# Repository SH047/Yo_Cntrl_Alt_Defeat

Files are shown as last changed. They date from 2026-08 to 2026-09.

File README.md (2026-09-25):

# WRO 2026 Future Engineers

## Team YO_CNTRL_ALT_DEFEAT - Version 2

| | |
| --- | --- |
| **Team name** | YO_CNTRL_ALT_DEFEAT |
| **Team ID** | 1680 |
| **Team members** | Abhay and Nidhella |
| **Country / region** | India |
| **Season** | 2026 - Future Engineers |

This repository documents Version 2 of the YO_CNTRL_ALT_DEFEAT autonomous vehicle for WRO Future Engineers. V2 is a rear-wheel-drive vehicle with servo-driven front-wheel steering and a mechanical rear differential. A **single ESP32 DevKit V1** runs every real-time task. It reads three VL53L0X time-of-flight (ToF) sensors (plus an optional rear sensor) through a TCA9548A I2C multiplexer, takes heading from a BNO055 IMU, measures distance from a quadrature encoder on a JGB37-520 geared motor, and drives the steering servo and motor driver. Colour recognition is handled on board by a **HUSKYLENS AI camera**, which reports coloured blocks to the ESP32 over I2C. No separate vision computer is carried on V2.

## V1 baseline

<p align="center">
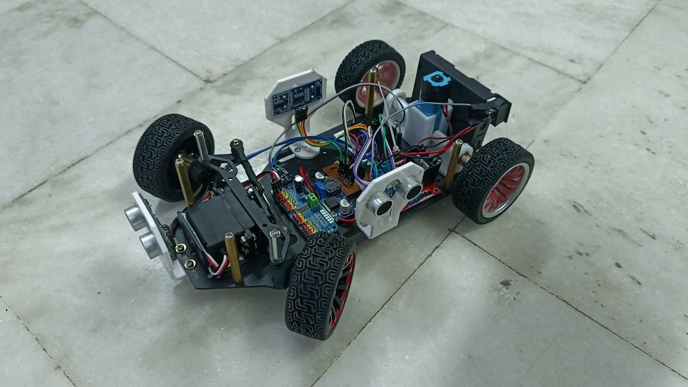
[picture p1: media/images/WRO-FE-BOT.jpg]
YO_CNTRL_ALT_DEFEAT Version 1 robot
  
</p>

<p align="center"><em>Version 1 prototype. This image remains as the visual baseline for the V2 design record.</em></p>

| Area | V2 implementation | Measured evidence |
| --- | --- | --- |
| Mobility | Rear-wheel drive through a mechanical differential, servo-driven front-wheel steering | Open round 23/25 successful runs; heading error after each corner ±2-4° |
| Feedback | Quadrature encoder, BNO055 IMU, 3 × VL53L0X ToF (+1 optional rear) | Encoder calibration ±2 ticks per metre; ToF ±7-10 cm at 2 m |
| Compute | Single ESP32 DevKit V1 + HUSKYLENS AI camera (on-camera colour recognition) | Start-up device check; pillar pass rate 44/50 |
| Fabrication | Acrylic chassis plate with 3D-printed PETG mounts from the STL library | Fitted STL set recorded in the engineering documentation (§2.6) |

## Documentation

| Resource | Purpose |
| --- | --- |
| [Engineering documentation](docs/) | Full V2 engineering documentation (PDF): design rationale, pin map, calibration, strategy, test results |
| [V2 engineering journal](docs/V2_ENGINEERING_JOURNAL.md) | Design rationale, V1-to-V2 change log, risks and validation plan |
| [`Codes/`](Codes/) | Competition programs for the open and obstacle rounds (ESP32) |
| [V2 STL library](hardware/STL_V2/) | 31 supplied STL files and fabrication notes |
| [V2 electronics reference](hardware/ELECTRONICS_V2/) | Component architecture, wiring rules and bench-test worksheet |
| [Bill of materials](hardware/) | `Yo_Cntrl_Alt_Defeat BOM.csv` |
| [Robot photographs](media/images/v2/) | V2 robot views and wiring photograph |
| [Mock run video](media/videos/) | `v2-MockRun-OpenRound.mp4` |
| [`src/`](src/) | Earlier code snapshots |

## V2 system architecture

```mermaid
flowchart LR
    Husky["HUSKYLENS AI camera<br/>On-camera colour recognition"] -->|"I2C: colour blocks (x, y, w, h, ID)"| ESP["ESP32 DevKit V1<br/>Sensing, decisions and actuation"]
    ESP <-->|I2C| Mux["TCA9548A<br/>I2C multiplexer (0x70)"]
    Mux -->|ch 0| ToF1[Front ToF]
    Mux -->|ch 1| ToF2[Right ToF]
    Mux -->|ch 2| ToF3[Left ToF]
    Mux -->|ch 3| IMU["BNO055 IMU<br/>Absolute heading"]
    Mux -.->|"ch 6 (optional)"| ToF4[Rear ToF]
    ESP -->|GPIO 13| Servo["RoboKit 20 kg<br/>steering servo"]
    ESP -->|"GPIO 26 PWM / 27 DIR"| Driver["7 Semi Vikram<br/>motor driver"]
    Driver --> Motor["JGB37-520 geared motor<br/>Quadrature encoder"]
    Motor -->|"Encoder A/B: GPIO 18 / 19"| ESP
    Start["START button"] -->|GPIO 25| ESP
    ESP -->|GPIO 14| Ring["NeoPixel ring<br/>Status"]
    ESP -.->|Bluetooth CSV log| Phone["Phone<br/>YoLabs-FE"]
```

V2 has one programmable controller. The HUSKYLENS is treated as a smart sensor: it captures frames, runs the trained colour-recognition model, and returns a short list of coloured blocks with their position, size and learned ID. The ESP32 requests these blocks every loop, filters them by shape, reads the ToF sensors, IMU and encoder, runs the open-round and obstacle-round state machines, drives the servo and motor, and logs every loop over Bluetooth.

## V1 and V2 comparison

| Area | V1 prototype | V2 robot | Why it matters |
| --- | --- | --- | --- |
| Vision | Separate vision computer + camera with OpenCV, commands sent over UART | HUSKYLENS AI camera on the ESP32 I2C bus | One controller owns the whole decision; no serial link to fail; colour model trained on the field |
| Distance sensing | Three HC-SR04 ultrasonic sensors, 5 V ECHO dividers | 3 × VL53L0X ToF (+ optional rear) via TCA9548A | Narrow beam, 3.3 V native, continuous ranging, no level shifting |
| Drive | BO motor, time-based distance | JGB37-520 geared motor + quadrature encoder, rear differential | Distance in millimetres; stall detection; smoother cornering |
| Heading | Basic / none | BNO055 absolute heading with PD control | Straight legs and exact 90° corners |
| Power | 9 V supply, one buck converter | 12 V LiPo, separate motor, servo and logic branches | Motor and servo surges kept off the logic rail |
| Run feedback | USB serial only | Bluetooth CSV log ("YoLabs-FE") + NeoPixel status ring | Every practice run produces data for tuning |
| Mechanical platform | Prototype steering chassis | Acrylic chassis plate with 3D-printed PETG mounts and bearing supports | Improved alignment and easier component replacement |

## Advantages of V2

1. The encoder and BNO055 IMU make every manoeuvre distance- and heading-based, so battery voltage no longer changes where the robot turns.
2. Narrow-beam ToF sensors at the front, left and right (plus an optional rear sensor) measure the wall they point at, not the nearest object in a wide acoustic cone.
3. The rear differential lets each rear wheel turn at its own speed in corners, reducing tyre scrub and heading disturbance with only one motor, one driver and one encoder.
4. Separate motor, servo and logic power branches stop motor or steering surges from browning out the ESP32 or the HUSKYLENS.
5. Moving colour recognition into the HUSKYLENS removes the second computer, its boot sequence and the serial link, so there are fewer failure points at the start line.
6. Colours are learned on the actual field with a button press, so re-training under venue lighting takes minutes.
7. Every loop is logged as a CSV line over Bluetooth, so each practice run leaves data for tuning.

## Hardware list

| Item | Qty | Role in the robot |
| --- | --- | --- |
| HUSKYLENS AI camera | 1 | Colour recognition of red / green traffic signs and blue / orange corner lines |
| ESP32 DevKit V1 | 1 | Single real-time controller; Bluetooth logging |
| VL53L0X time-of-flight sensor | 3 (+1) | Front, right and left distance; optional rear sensor for corner reverse |
| TCA9548A I2C multiplexer | 1 | Gives each same-address VL53L0X (and the IMU) its own channel |
| BNO055 9-axis IMU | 1 | Absolute heading for straight-line and corner control |
| JGB37-520 DC geared motor (120 RPM) | 1 | Rear-wheel propulsion |
| Quadrature motor encoder | 1 | Distance travelled and stall detection |
| Mechanical differential + drive shafts | 1 + 2 | Splits drive to the rear wheels while allowing different speeds in turns |
| RoboKit 20 kg high-torque servo | 1 | Front-wheel steering |
| 7 Semi Vikram motor driver | 1 | PWM speed and direction control of the drive motor |
| 12 V LiPo battery | 1 | Primary energy source (XT60 connector) |
| Voltage regulators (5 V logic, servo) | 2 | Separate logic and servo supplies |
| WS2812B NeoPixel ring, 16 LED | 1 | Run-state and fault indication |
| START push-button, power switch | 1 + 1 | Run start / stop; master isolation |
| Wheels / tyres | 4 | Traction (large rear, small front) |
| Acrylic chassis plate + 3D-printed mounts | 1 set | Structure |
| Jumper wires, power cables, perfboard | as required | Interconnection |

## Image record
> **V2 front-left view**<br>
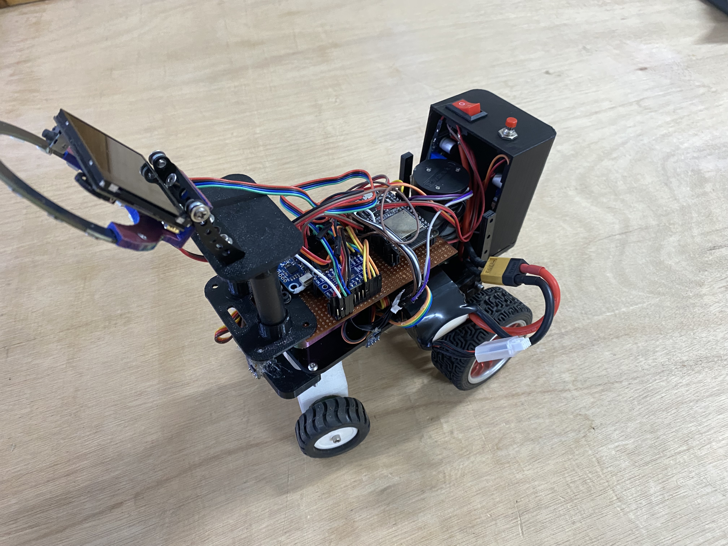
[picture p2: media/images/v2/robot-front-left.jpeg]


> **V2 top view**<br>
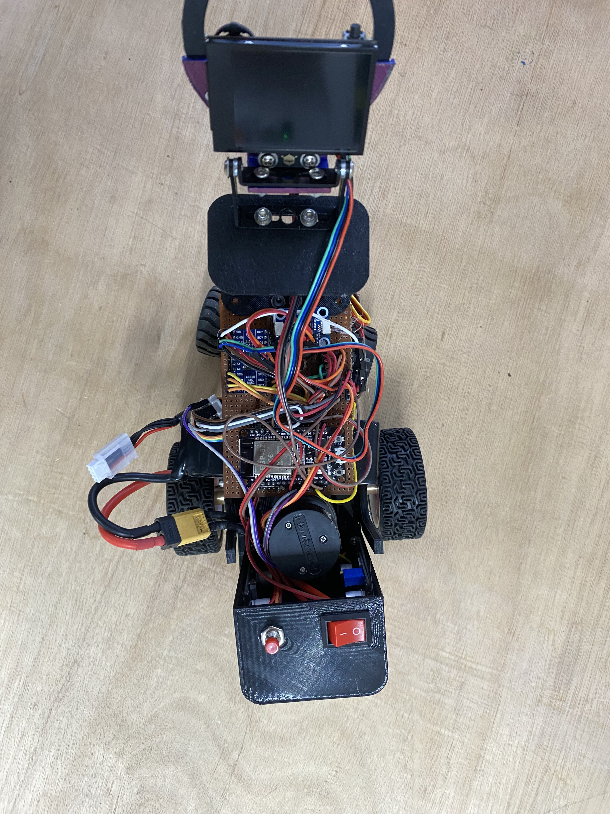
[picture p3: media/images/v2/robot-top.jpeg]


> **V2 right-side view**<br>
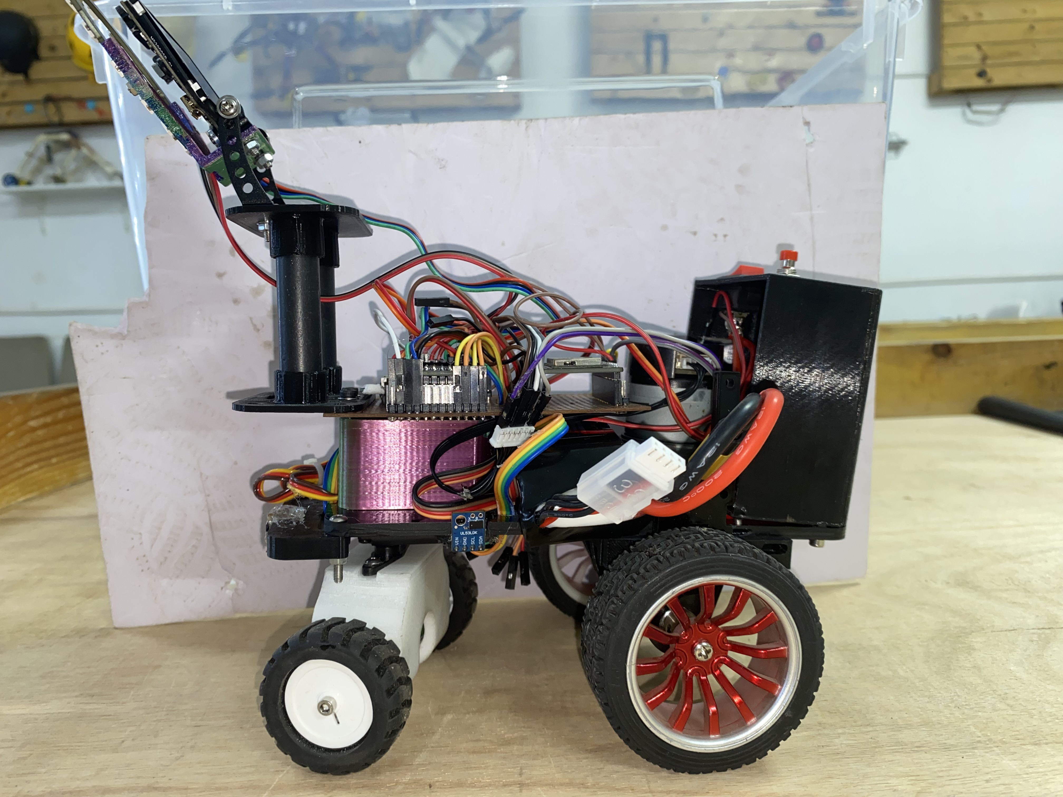
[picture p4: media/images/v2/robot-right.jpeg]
 

> **V2 back**<br>
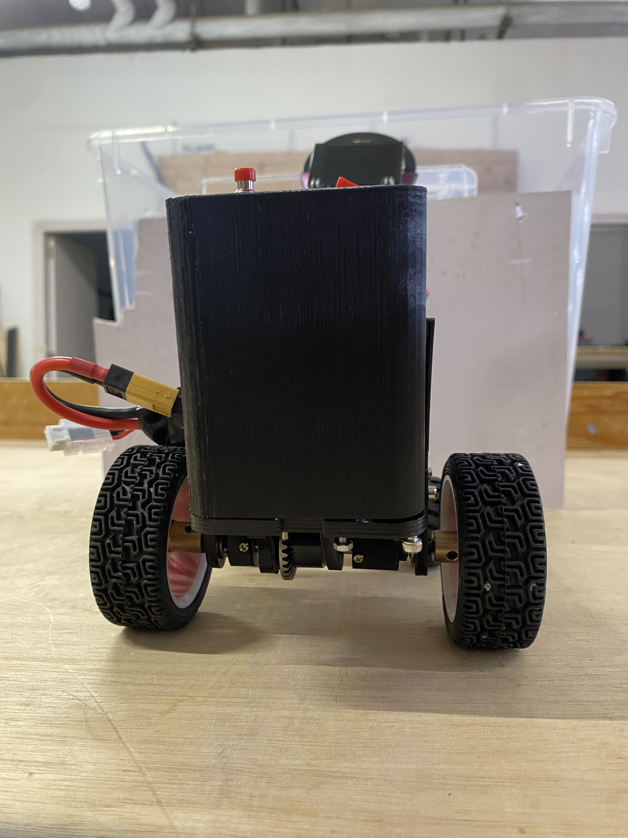
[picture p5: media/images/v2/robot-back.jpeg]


> **V2 wiring view**<br>
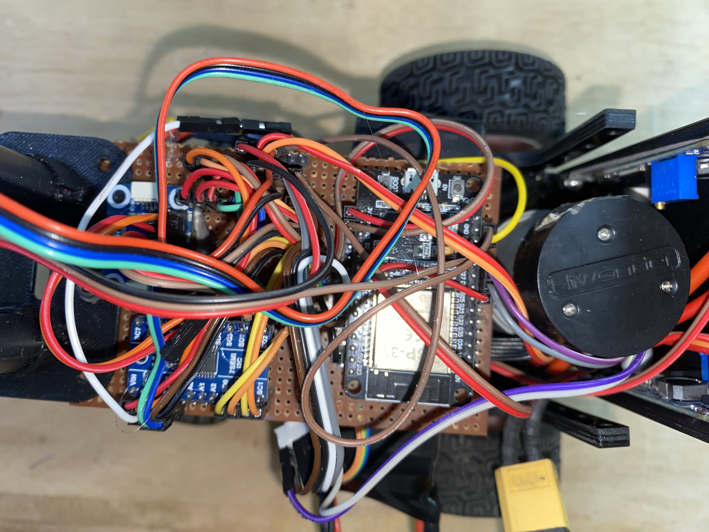
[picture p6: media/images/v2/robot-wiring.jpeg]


## Electrical power flow

```mermaid
flowchart TD
    Battery["12 V LiPo (XT60)"] --> Fuse[Main fuse and power switch]
    Fuse --> MotorRail[Motor branch]
    Fuse --> ServoReg[Servo regulator]
    Fuse --> LogicReg[5 V logic regulator]
    LogicReg --> ESP["ESP32 DevKit V1 (VIN)"]
    LogicReg --> Husky[HUSKYLENS]
    LogicReg --> Ring[NeoPixel ring]
    ESP --> SensorRail["3.3 V from ESP32 regulator"]
    SensorRail --> Mux[TCA9548A]
    SensorRail --> IMU[BNO055]
    SensorRail --> ToF["VL53L0X ToF × 3 (+1)"]
    MotorRail --> Driver[7 Semi Vikram motor driver]
    Driver --> Motor[JGB37-520 geared motor]
    ServoReg --> Servo[20 kg steering servo]
    Ground[Single common ground node] --- MotorRail
    Ground --- ServoReg
    Ground --- LogicReg
```

The servo is never powered from the ESP32 or from the 5 V logic rail, because a 20 kg servo stalling at full lock can pull enough current to brown out the ESP32 and reset the run. Battery, motor driver, both regulators, ESP32, servo, HUSKYLENS and all I2C sensors share one ground node. Before integration, verify polarity, measure each regulator output with no load, and confirm that every I2C device answers while PWM is active.

## ESP32 pin assignment

| Component | Connection | ESP32 pin |
| --- | --- | --- |
| Motor driver IN1 | Speed / PWM | GPIO 26 |
| Motor driver IN2 | Direction | GPIO 27 |
| Steering servo | Signal (50 Hz PWM, 500-2400 µs) | GPIO 13 |
| Encoder channel A | Interrupt, rising edge | GPIO 18 |
| Encoder channel B | Direction input | GPIO 19 |
| START button | Input, internal pull-up, active low | GPIO 25 |
| NeoPixel ring | Data in | GPIO 14 |
| I2C SDA | HUSKYLENS + TCA9548A | GPIO 21 (default) |
| I2C SCL | HUSKYLENS + TCA9548A | GPIO 22 (default) |
| Common ground | GND | ESP32 GND |

SDA / SCL are not set explicitly in the code (`Wire.begin()`), so the DevKit V1 defaults GPIO 21 / 22 apply. The I2C bus runs at 100 kHz.

**TCA9548A channels:** ch 0 → front ToF, ch 1 → right ToF, ch 2 → left ToF, ch 3 → BNO055, ch 6 → rear ToF (optional). The HUSKYLENS sits on the main bus, which stays connected whatever channel is selected.

## HUSKYLENS colour IDs

| ID | Colour | Field element | Used for |
| --- | --- | --- | --- |
| 1 | Blue | Corner line | Corner confirmation (line gate) |
| 2 | Orange | Corner line | Corner confirmation (line gate) |
| 3 | Magenta | Parking-lot marker | Logged only |
| 4 | Red | Traffic sign | Pass on the right |
| 5 | Green | Traffic sign | Pass on the left |

Learn each colour ID on the actual field under the venue lighting before running.

## Program set

Each round has its own program in [`Codes/`](Codes/), so a change for one round cannot break the other. All tuning constants are `#define` values at the top of each program.

| File | Round | Status | Summary |
| --- | --- | --- | --- |
| `01_Complete_Open_Round_CW_CCW.ino` | Open | Competition | Heading PD + wall centring, ToF corner detection, auto CW / CCW lock, 12 turns then finish |
| `03_Obstacle_Round_With_Parking_Out_Corrected.ino` | Obstacle | Competition | Parking exit, pillar bulges, gated precision corners, optional rear-ToF reverse |
| `02_Obstacle_Round_No_Parking_Slow_Accurate.ino` | Obstacle | Fallback | Same strategy at PWM 70, no parking exit |

To flash a program, open the `.ino` file in the Arduino IDE with ESP32 board support, select the ESP32 DevKit V1 board, install the libraries listed in the program header (including the DFRobot HUSKYLENS library), and upload over USB.

## Control flow

```mermaid
flowchart TD
    Start[Power on] --> Check["Start-up device check:<br/>ToF channels, BNO055, HUSKYLENS"]
    Check -->|"Sensor missing"| Fault["Flash ring yellow, log channel,<br/>refuse to start"]
    Check -->|"HUSKYLENS not found"| Retry[Retry every 500 ms] --> Check
    Check -->|"Ready (ring warm white)"| Wait[Wait for START button]
    Wait --> Sense["Read HUSKYLENS blocks, ToF,<br/>BNO055 heading and encoder"]
    Sense --> Decide["Phase state machine:<br/>steering and speed target"]
    Decide --> Actuate[ESP32 sets servo angle and motor PWM]
    Actuate --> Log[Write CSV line over Bluetooth]
    Log --> Complete{"12 corners done<br/>and finish section driven?"}
    Complete -->|No| Sense
    Complete -->|Yes| Stop[Stop]
    Sense -->|"Obstacle round: front ToF ≤ 12 cm<br/>with corner gates failing"| Stop
```

The camera decides **what** to do (which side to pass a pillar, whether a corner line is present). The ToF sensors and encoder decide **when** and **whether it is safe**: a camera detection cannot start a corner without the distance, side and front gates, and the front ToF can stop the run whatever the camera sees.

## Measured test results

| Test | Method | Metric | Result |
| --- | --- | --- | --- |
| ToF accuracy | Flat target at a known distance of 2 m | Error in cm per channel | ±7-10 cm |
| Encoder calibration | Push 1 m along a straight edge | Ticks per metre | ±2 |
| Straight-line hold | Drive 2 m on heading PD | Lateral drift (°) | 5-10° |
| Corner accuracy | 12 corners in the open round | Heading error after each turn (°) | ±2-4° |
| Open-round reliability | Repeated full runs, CW and CCW | Successful runs / attempts | 23/25 |
| Pillar pass rate | Red and green pillars at all positions | Correct-side passes / attempts | 44/50 |
| Obstacle-round reliability | Full runs with random layouts | Successful runs / attempts | 12/20 |
| Parking exit | Repeated exits left and right | Clean exits / attempts | 14/15 |

## Build and validation flow

```mermaid
flowchart LR
    A[Select physical components] --> B[Dry-fit STL parts]
    B --> C[Mechanical roll and steering tests]
    C --> D[Power and motor-current tests]
    D --> E[Sensor, camera and Bluetooth-log bench tests]
    E --> F[Short straight and turn tests]
    F --> G[Full-course practice runs]
    G --> H[Freeze working calibration and backup]
```

## Repository structure

```text
README.md                         Main documentation
Codes/                            Competition programs (01, 02, 03) for the ESP32
docs/                             Engineering documentation (PDF) and V2 engineering journal
hardware/ELECTRONICS_V2/          Electronics reference and electrical validation plan
hardware/STL_V2/                  Printable STL parts + README
hardware/Yo_Cntrl_Alt_Defeat BOM.csv  Bill of materials
media/images/v2/                  Robot photographs
media/videos/                     v2-MockRun-OpenRound.mp4
src/                              Earlier code snapshots
```

## Build and bring-up procedure

Following this order means a fault is found while only one subsystem is connected. Section numbers (§) refer to the [engineering documentation](docs/).

1. Assemble the chassis, steering linkage, differential and motor mount; check the wheels turn freely and the steering does not bind at either lock.
2. Wire the common ground first, before any supply rail.
3. Power the regulators alone from the battery and set / measure each output before connecting any load.
4. Connect the ESP32 by USB only; flash a test and confirm Bluetooth logging reaches the phone.
5. Connect the I2C bus: HUSKYLENS, TCA9548A, ToF sensors and BNO055. Flash a program and confirm the start-up check passes (ring turns warm white).
6. Calibrate ToF offsets, encoder ticks per metre and servo centre (§3.9).
7. Learn the colour IDs on the HUSKYLENS on the field (§3.13).
8. With the wheels lifted, check motor direction, encoder sign and servo direction.
9. Run program `01_Complete_Open_Round_CW_CCW.ino` on the field at reduced speed, then at full speed, both directions.
10. Run program `03_Obstacle_Round_With_Parking_Out_Corrected.ino`, first without pillars, then with pillars; record the metrics from the Bluetooth log and note any changes made.

## Before a field run

1. Confirm the fitted STL parts match the actual motor, servo, bearings, differential and sensor boards.
2. Check that the steering has no mechanical bind and the wheels move freely.
3. Check the LiPo voltage, battery polarity (XT60), fuse, common ground and motor-driver current capacity.
4. Re-learn the HUSKYLENS colour IDs under the venue lighting.
5. Power on and confirm the start-up device check passes (ring turns warm white) and the Bluetooth log reaches the phone.
6. Load the saved calibration values and make a backup before changing gains.

## Security and configuration

Keep GitHub tokens, Wi-Fi passwords and event credentials out of tracked files. Use a local ignored configuration file and commit only a placeholder example.

<details>
<summary>V1 prototype reference (historical - superseded by V2 above)</summary>

> This section describes the earlier V1 robot (Raspberry Pi vision, HC-SR04 ultrasonic sensors, BO motor). It is kept for the design record only and does not describe the V2 hardware.

# Obstacle-Avoiding Robot

A rear-wheel-drive autonomous robot with front-wheel steering, three ultrasonic distance sensors, and Raspberry Pi computer vision. The Raspberry Pi uses a camera and OpenCV to detect obstacles/colours and sends high-level commands such as `dodgeRight()` and `dodgeLeft()` to an ESP32 over serial/UART. The ESP32 handles ultrasonic sensing, steering, and motor control.

## 1. System Architecture

```text
                 ┌──────────────────────┐
                 │     RASPBERRY PI     │
                 │                      │
                 │ Camera + OpenCV      │
                 │ Obstacle/colour      │
                 │ decision making      │
                 └──────────┬───────────┘
                            │
                       Serial / UART
                            │
                            ▼
                 ┌──────────────────────┐
                 │        ESP32         │
                 │                      │
                 │ Ultrasonic sensing   │
                 │ Servo steering       │
                 │ Motor control        │
                 └───────┬───────┬──────┘
                         │       │
              ┌──────────┘       └───────────┐
              ▼                              ▼
       ┌─────────────┐                ┌─────────────┐
       │ Servo motor │                │ Motor driver│
       │ Front steer │                │             │
       └─────────────┘                └──────┬──────┘
                                            │
                                            ▼
                                       Rear BO motor
                                       + rear wheels
```

The Raspberry Pi performs high-level visual processing. The ESP32 is responsible for real-time interaction with the physical hardware.

## 2. Main Hardware

- Raspberry Pi
- Raspberry Pi camera module
- ESP32 development board
- 3 × HC-SR04 ultrasonic sensors
- Servo motor for front-wheel steering
- BO motor
- Compatible single-channel motor driver with IN1, IN2 and ENA/PWM inputs
- 9 V battery/supply
- 9 V → 5 V buck converter
- Front steering mechanism and chassis
- Rear wheels connected to the BO motor
- Resistors for ultrasonic ECHO voltage dividers: 1 kΩ and 2 kΩ for each sensor
- Jumper wires and suitable power wiring

## 3. ESP32 Pin Connections

| Component | Connection | ESP32 pin |
|---|---|---|
| Front ultrasonic TRIG | TRIG | GPIO 13 |
| Front ultrasonic ECHO | ECHO | GPIO 34 |
| Left ultrasonic TRIG | TRIG | GPIO 14 |
| Left ultrasonic ECHO | ECHO | GPIO 35 |
| Right ultrasonic TRIG | TRIG | GPIO 25 |
| Right ultrasonic ECHO | ECHO | GPIO 32 |
| Motor driver IN1 | Motor control | GPIO 18 |
| Motor driver IN2 | Motor control | GPIO 19 |
| Motor driver ENA | PWM/speed | GPIO 15 |
| Servo signal | PWM | Use a free suitable GPIO |
| Common ground | GND | ESP32 GND |

GPIO 34 and GPIO 35 are input-only pins, which is appropriate for the ultrasonic ECHO signals.

## 4. Ultrasonic Sensor Wiring

Each HC-SR04 is connected as follows:

```text
HC-SR04 VCC  → 5 V
HC-SR04 GND  → GND
HC-SR04 TRIG → assigned ESP32 GPIO
HC-SR04 ECHO → voltage divider → assigned ESP32 GPIO
```

The HC-SR04 ECHO output can be approximately 5 V, while ESP32 GPIO is designed for 3.3 V logic. Do **not** connect a 5 V ECHO signal directly to an ESP32 input.

Use one voltage divider for every ECHO line:

```text
HC-SR04 ECHO
     │
    1 kΩ
     │
     ├────────────→ ESP32 ECHO GPIO
     │
    2 kΩ
     │
    GND
```

This produces approximately 3.3 V from a 5 V ECHO signal.

Make three identical dividers:

- Front ECHO → GPIO 34
- Left ECHO → GPIO 35
- Right ECHO → GPIO 32

The sensors should be physically positioned so that one faces forward and the other two face left and right.

```text
                    FRONT
                      ↑
                [FRONT SENSOR]

          [LEFT]                 [RIGHT]
          SENSOR                  SENSOR

                 ┌─────────┐
                 │  ROBOT  │
                 └────┬────┘
                      │
                   BO MOTOR
```

## 5. Power System

The 9 V supply powers the motor circuit and is also reduced to 5 V for the servo and ultrasonic sensors.

```text
                 9 V BATTERY
                ┌──────┴──────┐
                │             │
                ▼             ▼
          Motor driver    Buck converter
          motor supply       9 V → 5 V
                              │
                    ┌─────────┴─────────┐
                    ▼                   ▼
                 Servo VCC        Ultrasonic VCC
```

The ESP32 may be supplied through its appropriate 5 V/VIN input if the board and regulator specifications permit it. Check the exact ESP32 development board before connecting power.

All grounds must be common:

```text
Battery GND
   ├── Motor driver GND
   ├── Buck converter GND
   ├── ESP32 GND
   ├── Servo GND
   └── Ultrasonic GND
```

A common ground is essential because the ESP32 control signals need the same voltage reference as the devices receiving those signals.

## 6. Servo Wiring

The servo controls the front steering mechanism:

```text
Buck +5 V   → Servo VCC
Buck GND    → Servo GND
ESP32 GPIO  → Servo SIGNAL
```

Do not power the servo from an ESP32 GPIO. Steering against mechanical resistance can cause the servo to draw significant current, so the 5 V buck converter should supply the servo.

## 7. Motor Driver Wiring

The ESP32 controls the rear BO motor through the motor driver:

```text
ESP32 GPIO 18 ─────→ Motor driver IN1
ESP32 GPIO 19 ─────→ Motor driver IN2
ESP32 GPIO 15 ─────→ Motor driver ENA/PWM
ESP32 GND ──────────→ Motor driver GND

9 V battery ────────→ Motor driver motor-power input

Motor driver OUT1 ──→ BO motor
Motor driver OUT2 ──→ BO motor
```

The exact power and output terminals depend on the motor-driver module. Verify its pin labels and voltage/current ratings before connecting the motor.

Example ESP32 definitions:

```cpp
#define MOTOR_PIN_1 18
#define MOTOR_PIN_2 19
#define ENA 15
```

## 8. Raspberry Pi and Camera

Connect the camera module to the Raspberry Pi using the appropriate camera connector and configure the Raspberry Pi camera software for the installed operating system.

The software flow is:

```text
Camera
   ↓
Image capture
   ↓
OpenCV processing
   ↓
Obstacle/colour detection
   ↓
High-level decision
   ↓
"dodgeRight()" / "dodgeLeft()"
   ↓
UART/Serial
   ↓
ESP32
```

OpenCV can be used for image preprocessing, colour detection, contour/object detection, and other required vision operations. The exact OpenCV algorithm depends on the type of obstacle or colour that must be detected.

## 9. Raspberry Pi–ESP32 Communication

A serial/UART connection is used to transfer commands from the Raspberry Pi to the ESP32.

A simple command protocol can be used, for example:

```text
RIGHT
LEFT
FORWARD
STOP
```

The Raspberry Pi sends the command after processing the camera image. The ESP32 receives the command and calls the corresponding control routine.

If physical UART pins are used, connect TX of the transmitting device to RX of the receiving device and RX to TX, with a common ground. Confirm the voltage levels and UART configuration of the specific Raspberry Pi and ESP32 setup before wiring.

## 10. Obstacle-Avoidance Logic

The three ultrasonic sensors provide spatial information around the robot.

For example:

```text
Left   = 15 cm
Front  = 20 cm
Right  = 80 cm
```

The right side has substantially more free space, so the robot can select a right-hand avoidance manoeuvre.

Another example:

```text
Left   = 80 cm
Front  = 20 cm
Right  = 15 cm
```

The left side has more clearance, so the robot can select a left-hand manoeuvre.

If an obstacle is directly ahead:

```text
Left   = 60 cm
Front  = 15 cm
Right  = 55 cm
```

the obstacle is primarily in the forward path, and the left/right distances can be compared to select the clearer direction.

A single ultrasonic sensor would only provide information about the distance in one direction. Three sensors allow the ESP32 to compare available clearance on both sides and make a more useful steering decision.

## 11. Control Responsibilities

The Raspberry Pi and ESP32 have separate responsibilities.

**Raspberry Pi**
- Captures camera images
- Runs OpenCV
- Detects obstacles/colours
- Makes high-level vision decisions
- Sends avoidance commands

**ESP32**
- Reads the three ultrasonic sensors
- Determines local obstacle clearance
- Controls the motor driver
- Controls the steering servo
- Executes commands received from the Raspberry Pi

This separation keeps computationally intensive vision processing on the Raspberry Pi while keeping time-sensitive hardware control on the ESP32.

## 12. Why This Architecture Works

The robot combines camera-based vision with direct distance measurement. The camera provides visual information that ultrasonic sensors cannot provide, while ultrasonic sensors provide direct proximity information that does not depend on image interpretation.

Front-wheel steering separates steering from propulsion:

```text
Servo → front-wheel steering
BO motor → rear-wheel propulsion
```

This makes the physical control system straightforward: the ESP32 changes the servo angle to steer while the motor driver controls the rear BO motor.

Before powering the complete system, verify polarity, common ground, regulator output voltage, motor-driver ratings, servo current requirements, and the 3.3 V limitation of ESP32 GPIO inputs. Test the motor, servo, and each ultrasonic sensor separately before running the complete obstacle-avoidance program.

</details>

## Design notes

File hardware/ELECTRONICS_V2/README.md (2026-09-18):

<div align="center">

# Version 2 Electronics

### YO_ERROR-404 · WRO Future Engineers 2026

| Design status | Control layout | Build record |
| :---: | :---: | :---: |
| **Integration reference** | Raspberry Pi + ESP32-C3 | Update after each bench test |

</div>

> [!IMPORTANT]
> This is the Version 2 electronics build reference. Confirm board labels, connector polarity, current ratings and final pin assignments on the physical robot before powering it.

| [Architecture](#system-architecture) | [Components](#component-register) | [Wiring](#power-and-wiring) | [Pins](#pin-map-worksheet) | [Bring-up](#bench-bring-up) |
| :---: | :---: | :---: | :---: | :---: |

---

## System architecture

```mermaid
flowchart LR
    Battery[Main battery] --> Switch[Fuse and master switch]

    subgraph Power[Protected power distribution]
        Switch --> MotorRail[Motor supply]
        Switch --> LogicReg[5 V logic regulator]
        Switch --> ServoReg[Dedicated servo regulator]
    end

    subgraph Compute[Compute and control]
        Pi[Raspberry Pi\nVision and mission] <-->|Commands, telemetry and heartbeat| ESP[ESP32-C3\nReal-time control]
    end

    subgraph Sensing[Feedback]
        Mux[TCA9548A\nI2C multiplexer] --> ToF[4 x VL53L0X\nToF sensors]
        IMU[BNO055 IMU]
    end

    subgraph Motion[Actuation]
        Driver[Brushed DC\nmotor driver] --> Motor[12 V encoder motor]
        Servo[Steering servo]
    end

    LogicReg --> Pi
    LogicReg --> ESP
    ESP --> Mux
    ESP --> IMU
    ESP --> Driver
    ESP --> Servo
    ServoReg --> Servo
    MotorRail --> Driver

    classDef power fill:#FFF4D6,stroke:#B7791F,color:#442C00;
    classDef compute fill:#E5F0FF,stroke:#2463A6,color:#102A43;
    classDef sensing fill:#E7F7EE,stroke:#2F855A,color:#123B27;
    classDef motion fill:#FCE8E8,stroke:#B83232,color:#541414;
    class Battery,Switch,MotorRail,LogicReg,ServoReg power;
    class Pi,ESP compute;
    class Mux,ToF,IMU sensing;
    class Driver,Motor,Servo motion;
```

| Decision layer | Raspberry Pi processes camera input and chooses the mission action. |
| --- | --- |
| Real-time layer | ESP32-C3 reads feedback, drives motor and steering outputs, and applies safety behaviour. |
| Power principle | Motor, steering and logic are supplied from protected branches with a planned common ground. |

---

## Component register

### Compute and sensing

| Component | Role | Interface | Supply | Integration check |
| --- | --- | --- | --- | --- |
| **Raspberry Pi 5, 4 GB** or compatible fitted board | Camera processing and navigation decisions | Camera interface and serial link | Regulated 5 V | Measure rail voltage while camera and processor are active. |
| **Wide-angle Raspberry Pi camera** | Detect course features and objects | Camera interface | From Raspberry Pi | Check focus, field of view and cable retention. |
| **ESP32-C3 development board** | Sensor polling, PWM, telemetry and safety checks | I2C, PWM, GPIO and serial | 5 V input / 3.3 V logic | Record the exact board revision before choosing pins. |
| **4 x VL53L0X ToF sensors** | Front, left, right and rear clearance measurement | I2C through multiplexer | 3.3 V | Test every channel and record its mounting offset. |
| **TCA9548A multiplexer** | Separates same-address ToF sensors into I2C channels | I2C | 3.3 V | Scan all channels before fitting sensors. |
| **BNO055 IMU** | Heading reference for turn correction | I2C | 3.3 V | Mount away from high-current wiring and calibrate after final assembly. |

### Motion and power

| Component | Role | Interface | Supply | Integration check |
| --- | --- | --- | --- | --- |
| **Brushed DC H-bridge** sized for measured motor current | Controls the 12 V encoder motor | PWM/direction or driver-specific inputs | Motor rail | Test free-run, protected stall and loaded current before selecting the final driver. |
| **Encoder geared motor** | Rear propulsion with speed and distance feedback | Motor output and ESP32-C3 digital inputs | 12 V motor rail; encoder per specification | Verify channel order and counts per wheel revolution. |
| **High-torque digital steering servo** | Turns the front steering mechanism | PWM | Dedicated regulated servo rail | Confirm voltage range and check for brownouts at full steering load. |
| **5 V DC-DC regulator** | Powers Raspberry Pi and controller electronics | Power rail | Main battery to 5 V | Confirm capacity with all logic loads enabled. |
| **Adjustable servo regulator** | Supplies steering without loading the logic rail | Power rail | Main battery to servo voltage | Set voltage with a meter before connecting the servo. |
| **Fuse, master switch and correctly sized wiring** | Isolates the robot and limits fault current | Power path | Main battery | Place the fuse close to the battery positive terminal. |

> [!NOTE]
> The final motor-driver model, servo model and all regulator ratings must match the measured load and the hardware actually fitted to Version 2.

---

## Communication boundary

The Raspberry Pi sends the requested vehicle action. The ESP32-C3 owns time-sensitive sensing, encoder capture, motor/servo outputs and safe stopping.

```text
COMMAND  CMD,<speed>,<steering>,<state>
TELEMETRY TEL,<front>,<left>,<right>,<rear>,<yaw>,<encoder>,<health>
```

> [!CAUTION]
> Stop propulsion whenever commands become stale, a sensor-health check fails, or the controller resets. Test this with the wheels raised before every field run.

---

## Power and wiring

| Rule | Implementation evidence |
| --- | --- |
| Protected input | Use a main fuse and master switch before the regulator branches. |
| Separate load paths | Keep motor, steering and logic supplies on their intended protected branches. |
| Common reference | Join grounds at one planned reference point so signal levels remain valid. |
| Noise control | Keep high-current motor and servo leads short and away from I2C and IMU wiring. |
| Mechanical reliability | Add strain relief to the camera cable, battery connector and motor-driver terminals. |
| Loaded-voltage test | Measure voltage at the Raspberry Pi and ESP32-C3 while steering and driving are active. |

Any reset or sensor dropout during the loaded-voltage test must be fixed before field testing.

---

## Pin-map worksheet

Assign final pins only after the exact ESP32-C3 board and motor driver are on the bench.

| Function | ESP32-C3 pin | Connected device | Bench result |
| --- | :---: | --- | :---: |
| I2C clock | To be assigned | TCA9548A and BNO055 | Pending |
| I2C data | To be assigned | TCA9548A and BNO055 | Pending |
| Motor PWM | To be assigned | Motor driver | Pending |
| Motor direction | To be assigned | Motor driver | Pending |
| Steering PWM | To be assigned | Steering servo | Pending |
| Encoder channel A | To be assigned | Encoder motor | Pending |
| Encoder channel B | To be assigned | Encoder motor | Pending |
| Raspberry Pi serial link | To be assigned | Raspberry Pi | Pending |

---

## Bench bring-up

| Step | Task | Completion evidence |
| :---: | --- | --- |
| 01 | Inspect polarity, fuse, switch operation and cable clearance with battery disconnected. | Visual inspection complete. |
| 02 | Power regulators with controllers disconnected and measure every rail. | Voltage readings recorded. |
| 03 | Power Raspberry Pi and ESP32-C3, then confirm stable serial communication. | Command and telemetry log saved. |
| 04 | Scan I2C, test each ToF channel and check IMU heading output. | Sensor scan and calibration record saved. |
| 05 | Test steering with wheels raised; then verify motor direction and encoder counts at low speed. | Steering, motor and encoder checks passed. |
| 06 | Remove the command heartbeat and introduce a sensor fault. | Safe stop confirmed. |

## Evidence to retain

| Area | Record |
| --- | --- |
| Power validation | Battery voltage, regulator voltages and loaded readings |
| Motor sizing | Free-run and loaded current observations; driver temperature |
| Sensor validation | ToF channel scan, measured offsets and IMU calibration status |
| Control validation | Serial log, steering limits, encoder direction and safe-stop result |

---

<sub>Original Version 2 build reference informed by the architecture themes in <code>Yo_Error_404_Engineering_Journal (1).pdf</code>. It does not reproduce the journal's wording, diagrams, images or pin map.</sub>

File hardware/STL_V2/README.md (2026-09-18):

# V2 STL fabrication library

This folder contains the 31 root-level STL files supplied for the YO_ERROR-404 V2 robot. It intentionally contains no editable CAD source, drawing or image files.

## How to use the library

1. Start with a physical dry-fit of motor, bearings, differential, steering linkage, camera and sensor brackets.
2. Treat the different `V2`, `V3`, `V4` and `V5` labelled files as alternative iterations. Do not print every differential holder or coupler for one robot.
3. Record the chosen filename, filament, infill, nozzle size and test date in the engineering journal before a final print.
4. Use PETG for structural load-bearing mounts unless a part-specific test proves another material is suitable.

## File groups

| Group | STL files |
| --- | --- |
| Chassis and axle support | `aachassis body_6mm poly_1pc.stl`, `aapoly_6mm_1pc_front axel support.stl`, `aaside bearing mount_3mm AL_2pc.stl`, `front bearing_6_12_holder.STL`, `side bearing plate mount.STL` |
| Differential and couplers | `V2`, `V3`, `V4` and `V5` differential-holder files, differential couplers, motor coupling and back gear mount |
| Steering | `Turning FE V1.stl`, steering couplers and V2 steering coupler files |
| Wheels and camera | front/rear wheel files plus the camera-mount variants |
| Motor and electronics mounts | `V2 Motor mount for FE.stl`, `dc motor mount.STL`, `back rpi mount.STL`, `side mount tf mini mount.STL` |

The exact assembly mapping remains an open V2 build decision. Confirm fit against the actual purchased components before fabricating final parts.

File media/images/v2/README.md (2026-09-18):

# V2 robot image placeholders

Add final V2 robot photographs here after the chassis, wiring and sensor positions are fixed. Use consistent lighting, a plain background and filenames that match the documentation.

| Filename | Required view | Documentation use |
| --- | --- | --- |
| `robot-front-left.jpg` | Complete robot at a front-left angle | README opening image |
| `robot-top.jpg` | Top view with components labelled | System-layout evidence |
| `robot-right.jpg` | Right-side drivetrain and sensor view | Mechanical and sensor evidence |
| `robot-wiring.jpg` | Power and wiring layout | Electrical architecture evidence |
| `robot-bottom.jpg` | Underside, steering and axle view | Chassis and steering evidence |

Do not upload personal information, credentials or unrelated photographs.

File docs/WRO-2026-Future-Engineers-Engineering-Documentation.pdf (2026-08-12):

### W O R L D R O B O T O L Y M P I A D 2 0 2 6

F U T U R E E N G I N E E R S C A T E G O R Y

# Engineering Documentation

## Autonomous Obstacle-Avoiding Vehicle

Submission details

Team name | YO_CNTRL_ALT_DEFEAT
Team ID | 1684
Team members names | Abhay, Vikrant, Nidhella
Country / region | INDIA
Season | 2026 — Future Engineers
Repository URL | https://github.com/SH047/Yo_Cntrl_Alt_Defeat
Document version | v1.0
Date | 12/08/2026

WRO 2026 Future Engineers — Engineering Documentation

Page 2

## Contents

### 1. System overview

Concept, architecture, division of responsibilities, hardware inventory

### 2. Mobility and mechanical design

Sub-systems, steering and drive configuration, torque and speed reasoning

### 3. Power and sensor architecture

Power tree, current strategy, sensor selection, placement, calibration, wiring

### 4. Software architecture and obstacle strategy

Master–slave split, modules, protocol, avoidance logic, state machine, testing

### 5. Systems thinking and engineering decisions

Subsystem interactions, constraints, trade-off register, risk register

### 6. Reproducibility and repository

Repository structure, README requirements, build and bring-up procedure
A. Appendix A — Wiring quick reference
Connection-by-connection build sheet

How this document maps to the judging rubric

Each rubric criterion is addressed by a dedicated section. Cross-references are given where a topic is naturally discussed in more than one place.

Rubric criterion | Addressed in | Principal evidence
1 — Mobility and mechanical design | Section 2 | Sub-system table, steering/drive configuration, torque–speed strategy, Figures 2 and 3
2 — Power and sensor architecture | Section 3, Appendix A | Power tree, current strategy, sensor selection and placement, calibration method, wiring diagrams, Figures 4–6
3 — Software architecture and obstacle strategy | Section 4 | Module decomposition, command protocol, avoidance logic, state machine, edge cases, Figures 7 and 8
4 — Systems thinking and engineering decisions | Section 5 | Subsystem interaction map, constraint list, trade-off register, risk register, Figure 9
5 — Reproducibility and repository quality | Section 6, Appendix B | Repository structure, README requirements, bring-up procedure, completion checklist

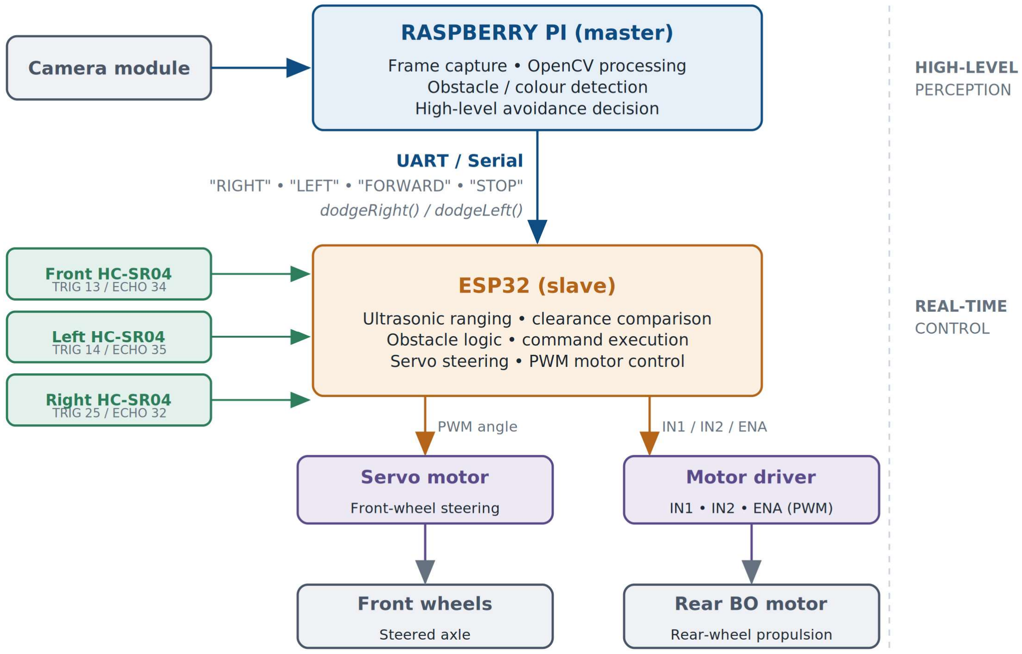
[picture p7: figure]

Page 3

## 1. System overview

### 1.1 Concept

The robot is a rear-wheel-drive autonomous vehicle with front-wheel steering, three ultrasonic distance sensors and Raspberry Pi computer vision. The Raspberry Pi uses a camera and OpenCV to detect obstacles and colours, and sends high-level commands such as dodgeRight() and dodgeLeft() to an ESP32 over a serial/UART link. The ESP32 handles ultrasonic sensing, steering and motor control.
The Raspberry Pi therefore performs high-level visual processing, while the ESP32 is responsible for real-time interaction with the physical hardware.

### 1.2 System architecture

Figure 1. System architecture. Perception and decision-making run on the Raspberry Pi; all real-time sensing and actuation run on the ESP32.

### 1.3 Division of responsibilities

The two controllers have separate and non-overlapping responsibilities. This keeps computationally intensive vision processing on the Raspberry Pi while keeping time-sensitive hardware control on the ESP32.

Page 4

Raspberry Pi — high-level perception | | ESP32 — low-level sensing and actuation
Captures camera images | | Reads the three ultrasonic sensors
Runs OpenCV | | Determines local obstacle clearance
Detects obstacles and colours | | Controls the motor driver
Makes high-level vision decisions | | Controls the steering servo
Sends avoidance commands over UART | | Executes commands received from the Raspberry Pi

### 1.4 Hardware inventory

Item | Qty | Role in the robot
Raspberry Pi | 1 | Vision host; runs OpenCV and issues avoidance commands
Raspberry Pi camera module | 1 | Image capture for the vision subsystem
ESP32 development board | 1 | Real-time controller for sensors, servo and drive motor
HC-SR04 ultrasonic sensor | 3 | Front, left and right distance measurement
Servo motor | 1 | Front-wheel steering actuation
BO motor | 1 | Rear-wheel propulsion

Single-channel motor driver with IN1, IN2 and
ENA/PWM inputs

### 1 Direction and speed control of the BO motor

9 V battery / supply | 1 | Primary energy source
9 V → 5 V buck converter | 1 | Generates the 5 V rail for the servo and sensors
Front steering mechanism and chassis | 1 | Structure and steering linkage
Rear wheels coupled to the BO motor | 2 | Traction
1 kΩ and 2 kΩ resistors | 3 pairs | ECHO voltage dividers (5 V → 3.3 V), one per sensor
Jumper wires and power wiring | as required | Interconnection

Page 5

## 2. Mobility and mechanical design

Rubric criterion 1 This section addresses rubric criterion 1: chassis design choices, steering and drive mechanism justification, torque/speed reasoning and mechanical stability.

### 2.1 Sub-systems of the robot

The robot is divided into the following major sub-systems.

Sub-system | Components used | Function
Mechanical / locomotion | Rear drive wheels, front steering mechanism, chassis | Provides movement and directional control
Drive and motor control | DC (BO) motor, motor driver, ESP32 | Controls the speed and direction of the rear drive motor
Steering | Servo motor, front steering mechanism | Changes the direction of the front wheels to steer the robot
Power supply | 9 V battery/supply, buck converter (9 V → 5 V) | Provides suitable voltages to the different electrical components
Obstacle detection | Three ultrasonic sensors at the front, left and right | Measures the distance to nearby obstacles
Vision | Raspberry Pi, camera module, OpenCV | Detects and identifies obstacles using image processing
Communication / control | Raspberry Pi and ESP32 serial link | Transfers obstacle information and directions from the vision system to the motor-control system
Central control | ESP32 | Processes sensor inputs and commands, and controls the motor and steering actions
Obstacle avoidance | dodgeRight() and dodgeLeft() routines, steering and drive mechanisms | Determines and executes the appropriate manoeuvre to avoid an obstacle

How these sub-systems interact as a whole is described in Section 5.1.

### 2.2 Steering and rear-wheel driving configuration

The robot uses a front-wheel steering and rear-wheel driving configuration, similar to the basic arrangement of a conventional vehicle. The front wheel is connected to a servo motor, allowing the steering angle to be adjusted, while the rear BO motor provides the driving force.

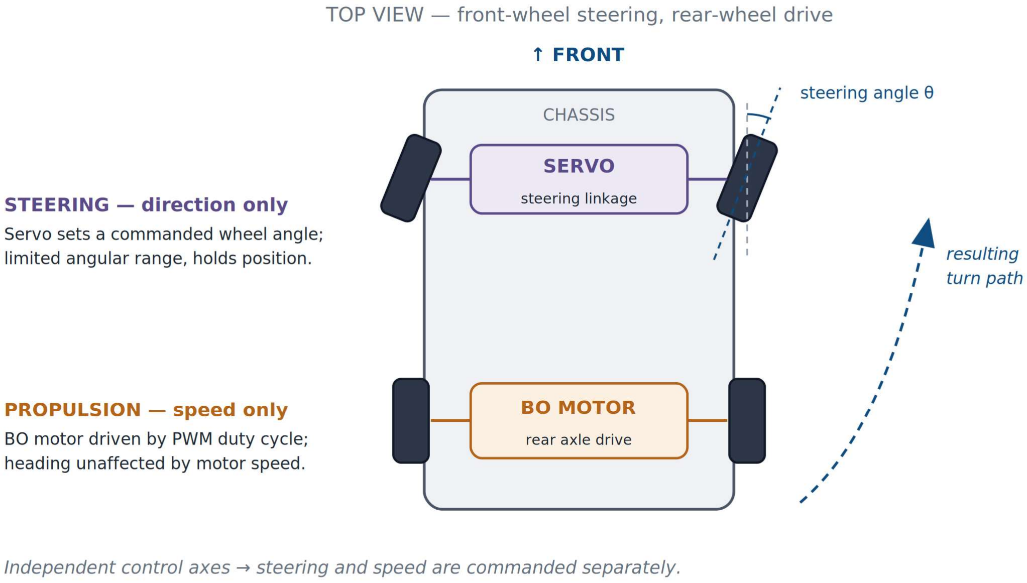
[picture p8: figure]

Page 6

Figure 2. Front-wheel steering with rear-wheel drive. Steering angle and drive speed are independent control axes.

This arrangement provides a clear separation between directional control and propulsion. The servo changes the robot's heading without changing the speed of the rear wheels, while the rear motor continuously supplies the force required to move the robot forward. This makes the control system relatively simple, because steering and motion can be controlled independently.
The arrangement also provides good manoeuvrability for obstacle avoidance. When an obstacle is detected, the steered wheel can be turned toward the side with greater available clearance while the rear motor continues to propel the robot. This produces a smooth turning motion rather than requiring independent control of multiple drive wheels.
The steering servo also provides sufficient torque to change the direction of the front wheel against the mechanical resistance from the robot's weight and its contact with the ground.

### 2.3 Rear-wheel drive through a motor driver

A rear-wheel-drive arrangement provides the robot's main propulsion, while the front wheels are dedicated to steering. The motor driver is necessary because an ESP32 GPIO pin cannot directly supply the current required by a DC motor; it also allows the ESP32 to control both the direction and the speed of the motor.
Why a motor driver rather than the alternatives:
- A motor driver provides separation between the low-power control electronics and the higher-current motor circuit.
- PWM control can be used to vary motor speed.
- Forward and reverse operation can be implemented by changing the motor-driver inputs.

Page 7

- Using a separate driver is more practical than attempting to drive the motor directly from the ESP32, which could damage the microcontroller.
- Compared with a more complex motor-control system, a conventional motor driver is simple, inexpensive and appropriate for a small mobile robot.

### 2.4 Front-wheel steering using a servo motor

The front wheels use a servo motor to control the steering angle. This allows the ESP32 to specify a particular steering position rather than simply turning a motor on or off.
Why a servo rather than the alternatives:
- A servo provides relatively precise angular positioning.
- It can maintain the required steering angle without requiring a separate position sensor in a typical setup.
- It is simpler to interface with the ESP32 than designing a steering mechanism using a DC motor and a feedback encoder.
- Compared with differential steering, front-wheel steering is more representative of conventional vehicle steering and can produce smoother directional changes.
- A servo is suitable when the steering mechanism only requires a limited angular range rather than continuous rotation.

### 2.5 Torque, speed and the variable-speed strategy

Variable speed control is important because the robot does not require the same speed in every situation. When the path is clear, the motor can operate at a higher PWM duty cycle, allowing the robot to travel faster. As an obstacle becomes closer, the motor speed can be reduced, giving the steering system more time to respond and reducing the distance required to slow down or stop.
The relationship between motor torque and speed matters here. For a DC BO motor, maximum torque is available at or near zero speed, while available torque generally decreases as motor speed increases. Reducing the commanded speed can therefore allow the motor to operate in a region where it can provide greater torque for a given load.
This is particularly beneficial during obstacle avoidance, because turning the steered wheel and moving the robot through a turn creates additional mechanical resistance. A lower speed gives better control and allows the motor to maintain sufficient torque while the robot is turning.
Situation | Commanded drive | Engineering reason
Obstacle far away | High PWM duty | Path is clear; travel time is minimised
Obstacle approaching | Reduce PWM duty | Gives the steering system more time to respond and shortens the distance needed to slow down

Page 8

Situation | Commanded drive | Engineering reason
Obstacle close | Low duty or stop | Shortest stopping distance; the motor sits nearer the high- torque part of its curve
Steering around the obstacle | Low duty maintained | Turning adds mechanical resistance, so torque margin is prioritised over speed
Obstacle cleared | Increase PWM duty | Return to cruise

Overall, variable-speed control improves both safety and manoeuvrability, and also helps the drive motor maintain useful torque when the robot is subjected to greater load during steering and obstacle avoidance.

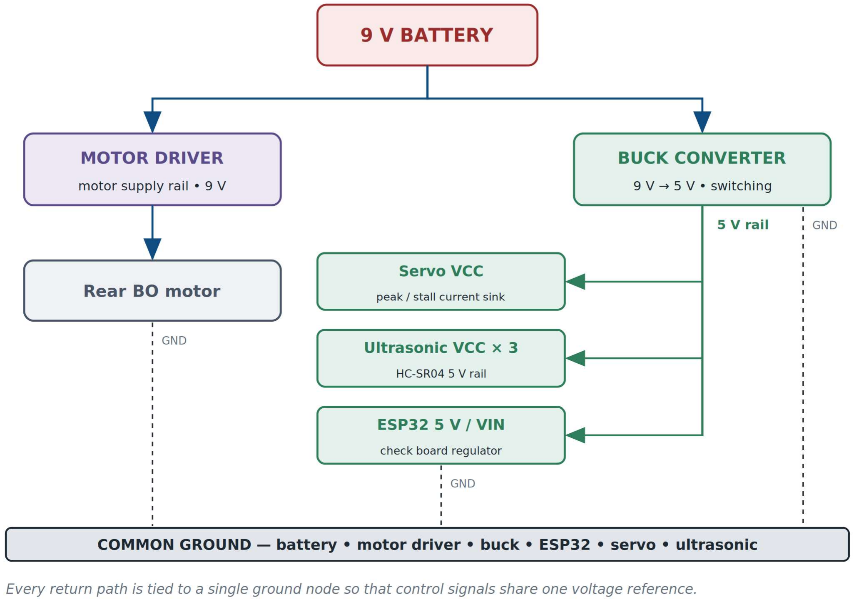
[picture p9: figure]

Page 9

## 3. Power and sensor architecture

Rubric criterion 2 This section addresses rubric criterion 2: power system architecture, current-draw reasoning, sensor selection justification, sensor placement and calibration, and wiring diagrams.

### 3.1 Power system architecture

The 9 V supply powers the motor circuit and is also reduced to 5 V for the servo and the ultrasonic sensors. Keeping the motor supply on the raw battery rail means that motor current transients are not drawn through the same regulator that feeds the sensing and control electronics.

Figure 3. Power distribution. The motor branch is taken directly from the battery; the buck converter feeds the 5 V logic and actuator rail.

The ESP32 may be supplied through its appropriate 5 V / VIN input if the board and regulator specifications permit it. The exact ESP32 development board must be checked before connecting power.

### 3.2 Common ground

All grounds must be connected together: battery ground, motor-driver ground, buck-converter ground, ESP32 ground, servo ground and ultrasonic ground. A common ground is essential because the ESP32 control signals need the same voltage reference as the devices receiving those signals.

Failure point A missing common ground is one of the most common causes of erratic behaviour in a mixed-voltage robot: signals appear to be present but are not interpreted correctly, because the receiving device measures them against a different reference.

Page 10

### 3.3 Buck converter for the 5 V rail

A buck converter reduces the approximately 9 V supply to 5 V for the servo motor and the ultrasonic sensors.
Why a buck converter rather than the alternatives:
- A servo normally requires a lower voltage than the main supply, so a direct connection to 9 V could damage it.
- A buck converter is more efficient than a linear regulator, because it dissipates substantially less power as heat when reducing voltage.
- It allows the existing higher-voltage supply to be converted to the required servo voltage without requiring a separate battery.
- It is particularly useful in a mobile robot, because power efficiency directly affects operating time.

### 3.4 Current strategy and power budget

Loads are allocated to rails according to how much current they draw and how abruptly that current changes. The drive motor is the largest and most abrupt load, so it is kept on the battery rail. The servo is the largest load on the 5 V rail because its current rises sharply when it steers against mechanical resistance; for this reason it is powered from the buck converter and never from an ESP32 GPIO pin.

Load | Rail | Load character | Indicative draw | Measured
BO motor (through the driver) | 9 V | Large, abrupt; highest at stall and on direction change | Motor- and load- dependent
Steering servo | 5 V (buck) | Low when idle, high peaks while steering against resistance | Servo-dependent; peak dominates sizing
HC-SR04 × 3 | 5 V (buck) | Small and steady while ranging | A few tens of mA in total
ESP32 board | 5 V / VIN | Moderate and continuous; rises when radios are active | Board-dependent
Raspberry Pi | Not yet allocated | Largest continuous logic load | See note below

▸ Measure each load with a multimeter in series (and note the peak while the servo stalls and while the motor starts). Enter the measured values in the last column, then confirm that the sum of the 5 V loads is within the buck converter's rated output current.
Open item The power tree above does not yet define a supply for the Raspberry Pi. Because the Pi's continuous current requirement is significantly higher than the other 5 V loads, this must be resolved before the final build — either by sizing the buck converter to carry it or by giving the Pi its own regulated supply. The decision, once made, belongs in Section 3.1.

Page 11

### 3.5 Sensor selection: three ultrasonic sensors

Three ultrasonic sensors are positioned at the front, left and right of the robot. They provide distance measurements around the robot rather than relying on information from a single direction.
Why ultrasonic sensors rather than the alternatives:
- Ultrasonic sensors directly measure the distance between the robot and an obstacle.
- They work independently of visible light, so their operation is less dependent on lighting conditions than camera-based distance estimation.
- They are relatively inexpensive and straightforward to interface with the ESP32.
- Sensors on the front, left and right give the robot information about possible escape directions.
- Infrared sensors could also be used, but their measurements are more affected by the reflectivity and surface characteristics of the obstacle.
- A LiDAR system could provide more detailed spatial information, but it would be more expensive and is unnecessary for basic obstacle-distance detection.
The ultrasonic sensors therefore provide a non-visual distance-sensing layer that complements the camera.

### 3.6 Sensor placement and coverage

The three sensors are mounted at the front, front-left and front-right. The front sensor primarily detects obstacles directly in the robot's path; the left and right sensors determine whether there is more free space on either side. Because the robot must steer before it reaches an obstacle, the side sensors are angled forward rather than square to the body, so that they measure the clearance the robot would actually turn into.

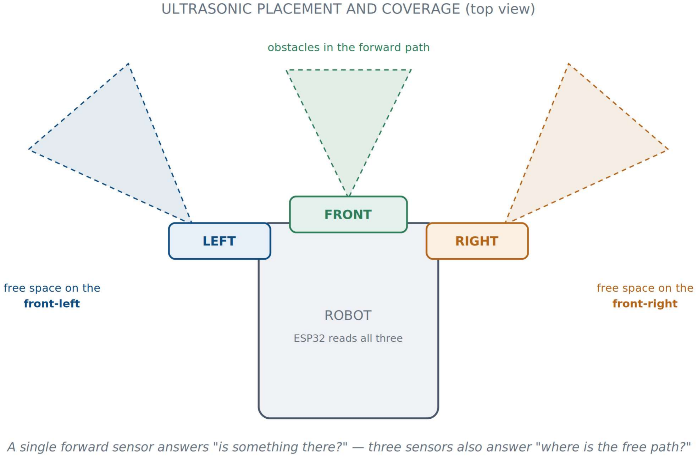
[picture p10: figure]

Page 12

Figure 4. Sensor placement and coverage. Forward-angled side sensors measure the clearance available in each candidate escape direction.

This arrangement provides considerably more information than a single ultrasonic sensor would:

Front | Left | Right | Possible response
Close | Far | Far | Reduce speed / turn
Close | Close | Far | Steer right
Close | Far | Close | Steer left
Close | Close | Close | Stop and reassess
Far | Far | Far | Continue forward
The three-sensor arrangement is therefore useful because obstacle avoidance requires not only detecting whether an obstacle exists, but also determining where the available path is. The sensors are handled by the ESP32, which allows distance measurements and steering/motor decisions to be made locally without requiring the Raspberry Pi to process every ultrasonic measurement.

### 3.7 Sensor calibration and threshold selection

Each HC-SR04 returns an echo pulse whose width is proportional to the round-trip time of flight. Distance is recovered from the pulse width using the speed of sound: the measured time is halved to account for the outbound and return path, then multiplied by the speed of sound (approximately 0.0343 cm/µs at room temperature). Because the speed of sound varies with temperature, and because each module has its own small offset, every sensor is calibrated individually before the thresholds are set.

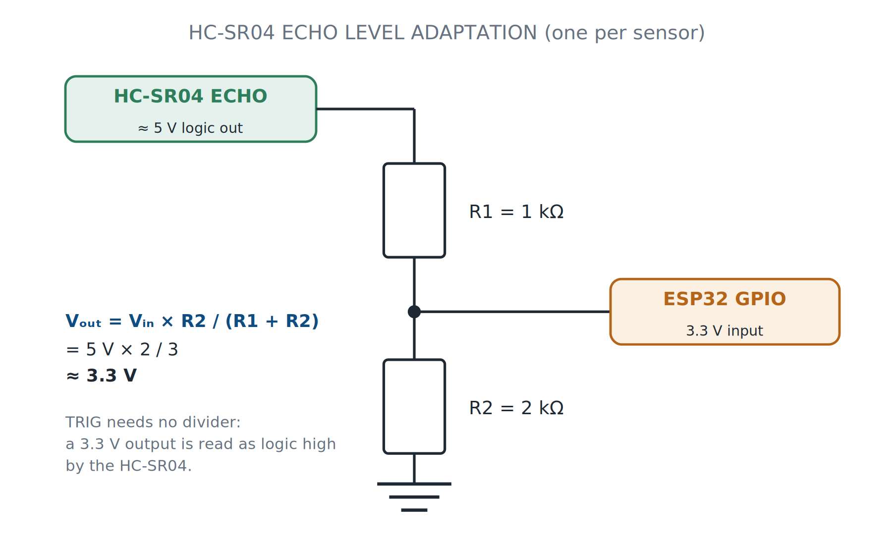
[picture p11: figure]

Page 13

Calibration procedure:
1. Mount the sensor in its final position on the robot — calibrating a sensor off the vehicle does not capture mounting angle or reflections from the chassis.
2. Place a flat target square to the sensor at a known distance and record the value reported by the firmware.
3. Repeat at several distances across the working range, and repeat each measurement a few times to see the spread.
4. Record the difference between the true and reported distance; if there is a consistent offset, apply it as a per-sensor correction in firmware.
5. Find the minimum reliable distance (below which the module stops returning a usable echo) and the maximum usable distance, and treat readings outside that band as invalid.

### 3.8 ECHO level adaptation

The HC-SR04 ECHO output can be approximately 5 V, while the ESP32 GPIO pins are designed for 3.3 V logic. A 5 V ECHO signal must not be connected directly to an ESP32 input. One voltage divider is used on every ECHO line.

Figure 5. ECHO voltage divider. One divider is built for each of the three sensors.

A 1 kΩ upper resistor and a 2 kΩ lower resistor produce approximately 3.3 V from a 5 V ECHO signal. Three identical dividers are required: front ECHO to GPIO 34, left ECHO to GPIO 35, and right ECHO to GPIO 32. The TRIG lines need no divider, because the 3.3 V output of the ESP32 is read as a logic high by the HC-SR04.

Page 14

### 3.9 ESP32 pin assignment

Component | Connection | ESP32 pin
Front ultrasonic | TRIG | GPIO 13
Front ultrasonic | ECHO (through divider) | GPIO 34
Left ultrasonic | TRIG | GPIO 14
Left ultrasonic | ECHO (through divider) | GPIO 35
Right ultrasonic | TRIG | GPIO 25
Right ultrasonic | ECHO (through divider) | GPIO 32
Motor driver IN1 | Direction control | GPIO 18
Motor driver IN2 | Direction control | GPIO 19
Motor driver ENA | Speed / PWM | GPIO 15
Servo signal | PWM | Free suitable GPIO — record the pin used
Common ground | GND | ESP32 GND

Note GPIO 34 and GPIO 35 are input-only pins on the ESP32, which is appropriate for the ultrasonic ECHO signals but means they cannot be reassigned to drive anything.

### 3.10 Servo wiring

The servo controls the front steering mechanism. Its supply comes from the buck converter, and only its signal line is connected to the ESP32:

Buck +5 V | → Servo VCC
Buck GND | → Servo GND
ESP32 GPIO | → Servo SIGNAL
The servo must not be powered from an ESP32 GPIO pin. Steering against mechanical resistance can cause the servo to draw significant current, so the 5 V buck converter supplies it.

### 3.11 Motor driver wiring

The ESP32 controls the rear BO motor through the motor driver:

ESP32 GPIO 18 ───→ Motor driver IN1
ESP32 GPIO 19 ───→ Motor driver IN2
ESP32 GPIO 15 ───→ Motor driver ENA / PWM
ESP32 GND | ───→ Motor driver GND
9 V battery | ───→ Motor driver motor-power input

Page 15

Motor driver OUT1 ──→ BO motor
Motor driver OUT2 ──→ BO motor
The exact power and output terminals depend on the motor-driver module, so its pin labels and voltage/current ratings must be verified against its datasheet before the motor is connected. Corresponding firmware definitions:

#define MOTOR_PIN_1 18

#define MOTOR_PIN_2 19

#define ENA | 15

### 3.12 Vision sensor: Raspberry Pi and camera

The camera module connects to the Raspberry Pi through the camera connector, and the Raspberry Pi camera software is configured for the installed operating system.
Why a Raspberry Pi and camera rather than relying only on ultrasonic sensors:
- Ultrasonic sensors provide distance information but cannot provide the same level of visual information about an object.
- A camera can distinguish visual features such as shape, colour, edges and position.
- OpenCV provides established image-processing functions without requiring a complete computer-vision system to be developed from scratch.
- The Raspberry Pi has substantially greater computational capability than a microcontroller such as the ESP32, making it more suitable for image processing.
- A conventional microcontroller alone would have limited resources for running relatively complex computer-vision algorithms.
The camera therefore complements the ultrasonic sensors: the sensors determine physical proximity, while computer vision provides visual information about the environment.

### 3.13 Failure points and pre-power-on checks

Failure point | Consequence | Mitigation
5 V ECHO connected directly to a 3.3 V GPIO | Damage to the ESP32 input | 1 kΩ / 2 kΩ divider on every ECHO line (§3.8)
Servo powered from a GPIO pin | Brown-out or GPIO damage when the servo loads up | Servo VCC taken only from the buck converter (§3.10)
Missing or partial common ground | Control signals not correctly referenced; erratic behaviour | Single ground node shared by every device (§3.2)
Motor driver under-rated for the motor | Overheating or driver failure | Verify the module's voltage and current ratings before connecting (§3.11)

Page 16

Failure point | Consequence | Mitigation
Buck output outside tolerance | Servo and sensors misbehave or are damaged | Measure the 5 V rail on the bench before any load is connected
Motor transients on the logic rail | ESP32 resets mid-run | Motor supply taken directly from the battery, not through the buck (§3.1)
Reversed battery polarity | Immediate damage to multiple modules | Check polarity at every connector before the first power-up

Before powering the complete system, verify polarity, the common ground, the regulator output voltage, the motor-driver ratings, the servo current requirement and the 3.3 V limitation of the ESP32 GPIO inputs. Test the motor, the servo and each ultrasonic sensor separately before running the complete obstacle-avoidance program.

Page 17

## 4. Software architecture and obstacle strategy

Rubric criterion 3 This section addresses rubric criterion 3: code modularity, state machines and flow logic, obstacle strategy, explanation of algorithms and code documentation.

### 4.1 Master–slave architecture

Using a Raspberry Pi as the master and an ESP32 as the slave suits an obstacle-avoiding robot because the two devices have different strengths.

The Raspberry Pi handles high-level vision
- The Raspberry Pi is powerful enough to run OpenCV and process camera images.
- It can identify obstacles or coloured objects such as red and green.
- This avoids putting computationally expensive image-processing tasks on the ESP32.

The ESP32 handles real-time control
- The ESP32 is well suited to directly controlling motors, motor drivers, ultrasonic sensors and encoders.
- It has a much more predictable real-time response than a Raspberry Pi running a full operating system.
- Once the Pi sends a command such as dodgeRight() or dodgeLeft(), the ESP32 can execute the corresponding movement immediately.

Consequences of the split

Property | Why the split delivers it
Reduced processing load | Image processing can consume considerable CPU resources. If the ESP32 were responsible for both camera processing and motor control, its resources would be more constrained. Separating the tasks lets each controller do the job it is best suited for.
Fast, reliable motor response | The ESP32 can continuously monitor sensors and control the motors without waiting for the Raspberry Pi to finish image processing — particularly useful when the robot must react quickly.
Modularity | The vision system and the motor-control system can be developed independently. The Pi could later use a more sophisticated object-detection model without major changes to the ESP32 software.
Fault isolation | If the camera-processing program encounters an error, the ESP32 still maintains control of the motors and sensors. Equally, changes to the motor-control code do not require modifying the vision system.

The architecture is therefore appropriate because it separates high-level computational tasks from low-level real-time control. The Raspberry Pi provides the processing power required for camera-based

Page 18

obstacle detection and decision-making, while the ESP32 provides fast, deterministic control of the robot's actuators. Communication between them is kept simple by transmitting short commands. This makes the robot more responsive, modular, scalable and computationally efficient than relying on either controller alone.

### 4.2 Module decomposition

Each responsibility is implemented as a separate module so that it can be tested on its own. The table below is the intended decomposition; module names in the repository should match this table.

Module | Host | Input | Output
Frame acquisition | Raspberry Pi | Camera module | Raw frame
Image pre-processing | Raspberry Pi | Raw frame | Resized, filtered, colour- converted frame
Obstacle / colour detection | Raspberry Pi | Pre-processed frame | Detected regions and their positions
Decision and command encoding | Raspberry Pi | Detected regions | Command string
Serial transmitter | Raspberry Pi | Command string | Bytes on the UART
Serial receiver and parser | ESP32 | Bytes on the UART | Validated command
Ultrasonic driver | ESP32 | TRIG/ECHO lines | Three distances in cm
Clearance arbitration | ESP32 | Command + three distances | Selected manoeuvre and target speed
Steering output | ESP32 | Selected manoeuvre | Servo angle
Drive output | ESP32 | Target speed and direction | IN1 / IN2 levels and ENA duty cycle

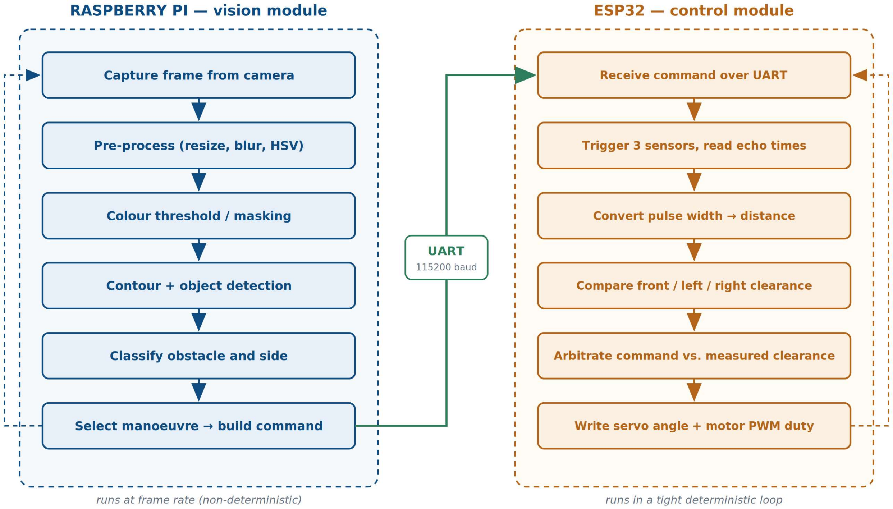
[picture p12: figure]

Page 19

Figure 6. Software flow. The Pi pipeline runs at frame rate; the ESP32 loop runs continuously and independently of it.

### 4.3 Vision pipeline

The vision subsystem runs on the Raspberry Pi and follows a fixed sequence: capture, pre-process, detect, decide, transmit.

Camera → image capture → OpenCV processing → obstacle / colour detection
→ high-level decision → "dodgeRight()" / "dodgeLeft()" → UART → ESP32
OpenCV is used for image pre-processing, colour detection, contour and object detection, and the other vision operations required. The exact algorithm depends on the type of obstacle or colour that must be detected.
Why OpenCV rather than writing the image processing from scratch:
- It provides established functions for image acquisition, filtering, thresholding, edge detection, contour detection and object detection.
- It reduces development time.
- It is open-source and widely supported.
- It is compatible with the Raspberry Pi and with both Python and C++ environments.
- Using a software library makes the vision subsystem easier to modify and test.
Dedicated computer-vision hardware could reduce the processing load on the Raspberry Pi, but would add hardware complexity and cost.

Page 20

### 4.4 Command protocol

A serial/UART connection transfers commands from the Raspberry Pi to the ESP32. The Raspberry Pi sends a command after processing the camera image; the ESP32 receives it and calls the corresponding control routine.

Command | Meaning | ESP32 action
FORWARD | Path is clear | Hold the steering centred and drive at the cruise
duty cycle
LEFT | Obstacle should be passed on the left —
dodgeLeft()

Steer toward the left at reduced speed, subject to measured clearance

RIGHT | Obstacle should be passed on the right —
dodgeRight()

Steer toward the right at reduced speed, subject to measured clearance

STOP | Motion must cease | Set drive duty to zero and hold position

If physical UART pins are used, the TX of the transmitting device connects to the RX of the receiving device and vice versa, with a common ground. The voltage levels and UART configuration of the specific Raspberry Pi and ESP32 setup must be confirmed before wiring.

### 4.5 Obstacle-avoidance logic

The three ultrasonic sensors provide spatial information around the robot, so the ESP32 can determine not only that an obstacle is present but where the free path is.

Scenario | Left | Front | Right | Decision
Obstacle on the left | 15 cm | 20 cm | 80 cm | The right side has substantially more free space, so a right-hand avoidance manoeuvre is selected
Obstacle on the right | 80 cm | 20 cm | 15 cm | The left side has more clearance, so a left-hand manoeuvre is selected
Obstacle directly ahead | 60 cm | 15 cm | 55 cm | The obstacle is primarily in the forward path; the left and right distances are compared and the clearer direction is selected

A single ultrasonic sensor would report only that something is roughly 20 cm away. Three sensors report that something is 20 cm ahead, that there is 15 cm of clearance on the left and 70 cm on the right — which is what makes a useful steering decision possible.

### 4.6 State machine

The behaviour described in Sections 2.5 and 4.5 is implemented on the ESP32 as an explicit state machine. Expressing it this way keeps speed and steering decisions in one place and makes the transitions testable one at a time.

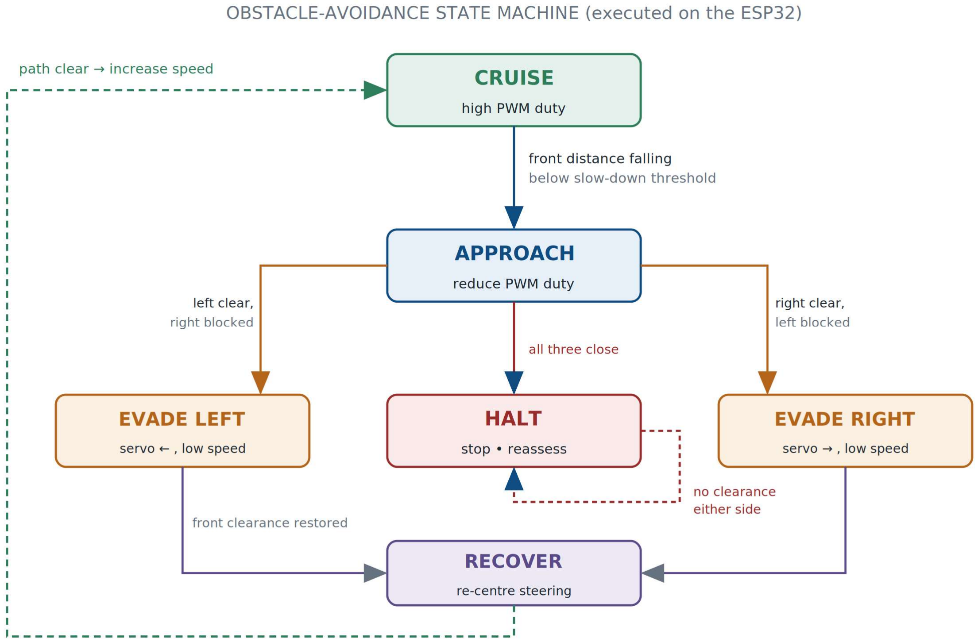
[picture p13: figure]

Page 21

Figure 7. Obstacle-avoidance state machine executed on the ESP32.

State | Entered when | Actuator outputs | Leaves for
CRUISE | All three clearances are large | Steering centred; high PWM duty | APPROACH when the front distance falls below the slow-down threshold
APPROACH | Front distance below the slow-down threshold | Steering centred; reduced PWM duty | EVADE LEFT, EVADE RIGHT or HALT once the side clearances are compared
EVADE LEFT | Front blocked, left clearance greater | Servo to the left limit; low PWM duty | RECOVER when front clearance is restored; HALT if the left closes up
EVADE RIGHT | Front blocked, right clearance greater | Servo to the right limit; low PWM duty | RECOVER when front clearance is restored; HALT if the right closes up
HALT | All three clearances small, or no escape direction | Drive duty zero; steering held | APPROACH or CRUISE once a clearance reopens
RECOVER | The obstacle has been passed | Steering returned to centre; duty increasing | CRUISE once the path ahead is clear

### 4.7 Arbitration between vision and ultrasonic data

Both controllers can propose a manoeuvre, so the rule for resolving disagreement is stated explicitly. The Raspberry Pi command sets the preferred direction, because vision can distinguish what the obstacle is and can see it earlier. The measured ultrasonic clearance holds veto authority over that

Page 22

preference, because it is an immediate physical measurement taken by the controller that is actually driving the actuators, and it remains valid when the vision pipeline is slow, wrong or stopped.
Rule In practice: if the Raspberry Pi commands RIGHT but the right-hand sensor reports insufficient clearance, the ESP32 does not execute the turn. It evades to the clearer side, or halts if neither side is clear.

▸ Confirm that this matches the arbitration implemented in the firmware, and adjust the wording if the code gives priority differently.

### 4.8 Edge cases

Edge case | Why it happens | Handling

No echo received within the
timeout

The target is beyond range, angled away, or sound-absorbing

Treat the reading as ‘at least maximum range’ rather than as zero, and continue on the remaining sensors

Vision command conflicts
with measured clearance

The camera sees an obstacle the sensors do not, or vice versa

Measured clearance wins (§4.7)

All three clearances small The robot has entered a dead end or a corner

Enter HALT and reassess rather than committing to a turn that cannot complete

Serial link silent | The Pi is busy, still booting, or the
vision program has stopped

The ESP32 continues to run on ultrasonic data alone — the fault-isolation property described in §4.1

Partial or corrupted
command received

A byte is lost or the message is split across reads

Discard the fragment and retain the previous validated command

Obstacle detected while
already evading

A second obstacle appears mid-manoeuvre

Re-evaluate the clearances on each control cycle rather than running an evade manoeuvre open-loop

### 4.9 Testing, tuning and performance metrics

Each part of the strategy is validated with a measurement rather than by observation alone.

Test | Method | Metric | Result
Sensor accuracy | Flat target at known distances (§3.7) | Error in cm at each distance; spread across repeats
Stopping distance | Drive at each PWM duty toward a wall and command a stop | Distance travelled after the stop command, per duty cycle
Threshold validation | Approach an obstacle at cruise speed | Whether the robot stops or evades before contact, over repeated runs

Page 23

Test | Method | Metric | Result
Evade success rate | Repeated runs against obstacles placed left, right and centre | Successful avoidances out of total attempts
Control loop rate | Time the ESP32 main loop | Loop iterations per second
End-to-end latency | Timestamp from frame capture to servo movement | Milliseconds from camera to actuator
Turn clearance | Evade manoeuvre beside a wall | Minimum lateral gap maintained during the turn

▸ Record the measured results and, where a value led to a change, note the change in the iteration log in Section 5.6.

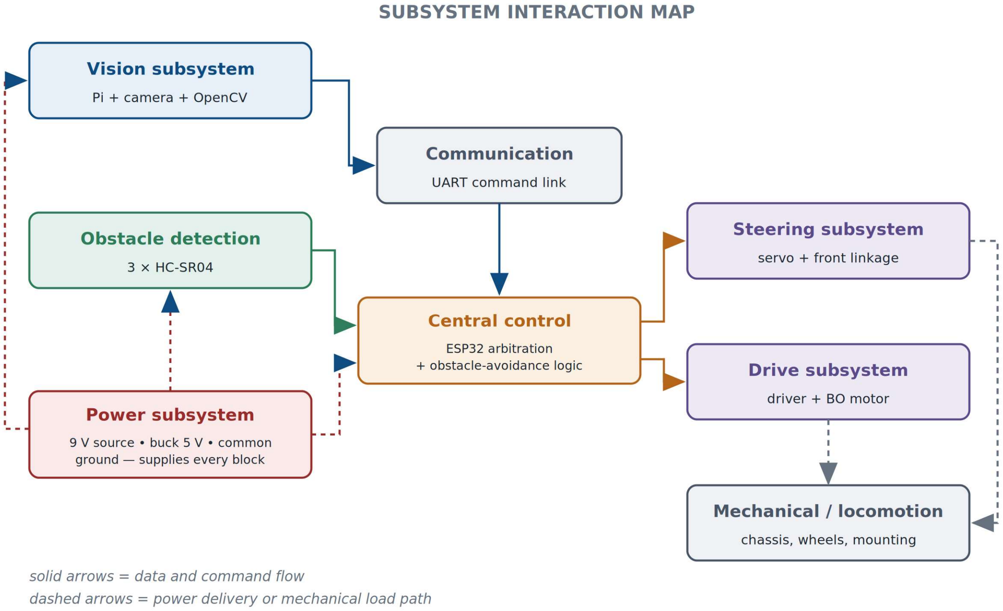
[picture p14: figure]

Page 24

## 5. Systems thinking and engineering decisions

Rubric criterion 4 This section addresses rubric criterion 4: how the subsystems work together, engineering reasoning for decisions, constraints and trade-offs, iteration and testing cycles, and risk identification and mitigation.

### 5.1 How the subsystems work together

The robot uses two complementary methods of obstacle detection. The ultrasonic sensors provide distance information from the front, left and right sides, while the Raspberry Pi camera provides visual information. OpenCV processes the camera images to detect obstacles. The Raspberry Pi then communicates the required direction, such as dodgeRight() or dodgeLeft(), to the ESP32. The ESP32 controls the motor driver and the servo motor to execute the avoidance manoeuvre.

Figure 8. Subsystem interaction map. Solid arrows carry data and commands; dashed arrows carry power or mechanical load.

### 5.2 Why the ESP32 is the low-level controller

The ESP32 acts as the low-level controller responsible for interacting with the robot's motors, servo and sensors. It receives directions from the Raspberry Pi and executes the corresponding manoeuvre.
Why not let the Raspberry Pi control everything directly:
- The ESP32 is well suited to real-time control of motors, servos and sensors.
- It has the GPIO, PWM and communication interfaces these components require.

Page 25

- Controlling motors and reading sensors is far less computationally demanding than what the Raspberry Pi is needed for.
- Separating high-level vision from low-level motor control prevents image-processing tasks from being responsible for precise motor timing.
- The ESP32 can keep handling time-critical hardware operations while the Raspberry Pi performs heavier vision processing.
- It is inexpensive and has low power consumption.

### 5.3 Why a master–slave split rather than a single controller

- The Raspberry Pi is better suited to computationally intensive image processing.
- The ESP32 is better suited to direct hardware control.
- Splitting the tasks reduces the computational burden on either device.
- The architecture is modular: the vision system and the motor-control system can be developed and tested separately.
- Hardware-level motor control stays on the ESP32 rather than depending on the operating-system timing of the Raspberry Pi.
This separation also makes it easier to replace or modify one subsystem without redesigning the entire robot.

### 5.4 Complementary sensing

The robot does not depend on a single sensing technique. It combines ultrasonic distance sensing with camera-based computer vision, because the two techniques have different strengths.

Technique | Main strength | Main limitation
Ultrasonic sensing | Direct distance measurement | Limited information about the appearance of the object
Camera and OpenCV | Provides visual information such as shape, colour and edges | Affected by lighting and requires more processing
Combined system | Complementary information and greater robustness | Greater hardware and software complexity

The camera provides visual information that ultrasonic sensors cannot, while ultrasonic sensors provide direct proximity information that does not depend on image interpretation. The detected information is converted into decisions such as dodgeRight() or dodgeLeft(), which the ESP32 then translates into steering and motor actions.

Page 26

### 5.5 Constraints and how the design responds to them

Constraint | Design response

ESP32 GPIO inputs are 3.3 V logic; HC-SR04
ECHO is approximately 5 V

A 1 kΩ / 2 kΩ divider on each ECHO line (§3.8)

GPIO 34 and GPIO 35 are input-only | They are assigned to ECHO inputs only, and are never used for TRIG
or actuator outputs (§3.9)

An ESP32 GPIO cannot supply motor current A motor driver stands between the controller and the BO motor (§2.3)

The servo draws high current when steering
against resistance

The servo is powered from the buck converter, never from a GPIO (§3.10)

A single 9 V source must serve motor, logic and actuators

The motor sits on the raw battery rail; a buck converter creates a separate 5 V rail (§3.1)

The servo has a limited angular range | Front-wheel steering is used, which needs limited travel rather than
continuous rotation (§2.4)

Camera performance depends on lighting Ultrasonic sensing provides a light-independent measurement layer (§5.4)

A full operating system gives non-deterministic timing

All time-critical actuation is executed on the ESP32 (§5.2)

Cost and complexity must stay proportionate to a small mobile robot

Ultrasonic rather than LiDAR; a standard motor driver rather than a specialised controller; a software library rather than dedicated vision hardware

### 5.6 Trade-off register

The table records the alternatives that were considered for each significant decision, and the reason for the option chosen.

Decision | Alternatives considered | Why the chosen option
Motor driver between the ESP32 and the BO motor | Driving the motor directly from a GPIO | A GPIO cannot supply motor current and could be damaged; the driver separates the high-current circuit and enables both PWM speed control and direction control
Front-wheel steering with a servo | Differential steering; a DC motor with an encoder for feedback | Precise angular positioning without an additional sensor, smoother directional change, simpler to interface, and only a limited angular range is needed
Buck converter for the 5 V rail | Linear regulator; a second battery | Substantially less power dissipated as heat, and no additional battery to carry; efficiency directly affects operating time

Page 27

Decision | Alternatives considered | Why the chosen option
Three ultrasonic sensors | One forward sensor; infrared sensors; LiDAR | Three sensors reveal where the free path is, not just that an obstacle exists; infrared is more affected by surface reflectivity; LiDAR is more expensive than the task requires
Camera and OpenCV on the Raspberry Pi | Ultrasonic sensing only; writing the vision code from scratch; dedicated vision hardware | Visual features such as shape, colour and edges become available; an established library shortens development; dedicated hardware would add cost and complexity
Raspberry Pi master with ESP32 slave | A single controller — either the Pi alone or the ESP32 alone | Deterministic actuation on the microcontroller, heavy vision on the Pi, independent development of each side, and fault isolation between them

### 5.7 Risk register

Electrical failure points are listed in Section 3.13. The risks below are system-level: they concern how the robot behaves rather than whether the hardware survives.

Risk | Effect if unmitigated | Mitigation
Lighting changes at the competition venue | Colour thresholds tuned elsewhere stop detecting obstacles | The ultrasonic layer is independent of light and continues to protect the robot (§5.4); thresholds re- checked on site

The vision program stops
or crashes

The robot would be left with no

| obstacle avoidance | The ESP32 keeps sensing and driving on its own data (§4.1, §4.8)

Timing jitter from the Pi's
operating system
Late or uneven actuator updates | All time-critical control runs on the ESP32 (§5.2)
Ultrasonic reading lost on an angled or soft surface | A missing echo is misread as an obstacle at zero distance | Out-of-range readings are treated as maximum range, not zero (§4.8)

Torque falls away during
a turn
The robot stalls mid-manoeuvre | Speed is reduced before and during the turn to keep
| | torque margin (§2.5)

Battery voltage sags over
a run

Motor speed and servo response

| drift as the battery discharges | Check performance on a low battery as well as a fresh one; record it in the test results (§4.9)

### 5.8 Iteration and testing cycles

Design changes made in response to test results are recorded here, so the reasoning behind the final configuration remains visible.

▸ Each row should tie back to a measurement in Section 4.9 — the strongest evidence for this criterion is a change that was made because of data rather than because of a hunch.

Page 28

## 6. Reproducibility and repository

Rubric criterion 5 This section addresses rubric criterion 5: repository structure and clarity, commit history, README structure, file organisation, inclusion of CAD, wiring and code files, and whether another team could reproduce the robot.

### 6.1 Repository structure

/
├── README.md | ← main documentation, ≥ 5000 characters
├── LICENSE
├── docs/
│ | ├── engineering-documentation.pdf
│ | ├── testing/ | ← measured results, logs, tuning notes
│ | └── decisions/ | ← trade-off and iteration records
├── hardware/
│ | ├── schematics/ | ← wiring diagrams and pin tables
│ | ├── cad/ | ← chassis and mount source files + exports
│ | └── bom | ← bill of materials
├── src/
│ | ├── esp32/ | ← firmware: sensors, servo, motor, serial parser
│ | └── raspberry-pi/ | ← vision pipeline and command transmitter
├── media/
│ | ├── photos/ | ← robot from every side
│ | └── video/ | ← or a link to the demonstration run
└── t-photos/ v-photos/ | ← team and vehicle photos, if required by the season

### 6.2 What each area must contain

Area | | Required contents
README.md | At least 5000 characters. Overview of the robot, subsystem summary, hardware list, wiring
summary, build instructions, how to run the software, and links into docs/
docs/ | This engineering documentation, plus the measured test results referenced from Sections

### 3.7 and 4.9

hardware/ | Wiring diagrams, the pin assignment table, CAD or mechanical drawings of the chassis and
mounts, and the bill of materials
src/esp32/ | Firmware, with the pin definitions, the ultrasonic driver, the arbitration logic and the state
machine each in their own file
src/raspberry-pi/ | The vision pipeline and the serial transmitter, with any tuning parameters kept in one place
rather than scattered through the code
media/ | Photographs of the assembled robot from each side, and a demonstration video or a link to
one

Page 29

### 6.3 Versioning and release notes

Each meaningful change to the robot or its documentation is recorded here and reflected in a tagged release, so that a judge or another team can tell which version of the repository matches the robot as presented.

Version | Changes
V1.0 | Initial engineering documentation
V2.0 | Doing laps without obstecles
V3.0 | Fully working bot

### 6.4 Repository quality checklist

| Requirement | Status
1 | README is at least 5000 characters and describes the whole system | [ ]
2 | At least three commits, with meaningful messages describing what changed and why | [ ]
3 | Code files present for both the ESP32 and the Raspberry Pi | [ ]
4 | Wiring diagrams present and readable | [ ]
5 | CAD or mechanical drawing files present | [ ]
6 | Bill of materials present | [ ]
7 | Testing workflow documented with measured results | [ ]
8 | Versioning or release notes included | [ ]
9 | Another team could rebuild the robot from the repository alone | [ ]

### 6.5 Build and bring-up procedure

Following this order means that a fault is found while only one subsystem is connected, rather than after everything is powered at once.
1. Assemble the chassis, mount the front steering linkage and fit the rear drive.
2. Wire the common ground first, before any supply rail is connected.
3. Power the buck converter alone and measure its output; confirm it is 5 V before connecting any load.
4. Build the three ECHO voltage dividers and measure each output while the sensor is triggered; confirm approximately 3.3 V.
5. Flash the ESP32 and test the BO motor on its own — direction and PWM speed range.

Page 30

6. Test the servo on its own across its full commanded range, checking the steering linkage does not bind at either limit.
7. Test each ultrasonic sensor separately against a known distance, and record the calibration values from Section 3.7.
8. Connect the Raspberry Pi and confirm that commands sent over the UART are received and parsed correctly, with the motors disabled.
9. Enable the motors and run the complete obstacle-avoidance program, starting at a low cruise duty cycle.
10. Record the measurements listed in Section 4.9 and log any resulting changes in Section 5.8.

Page 31

## Appendix A — Wiring quick reference

A single-page build sheet. Every connection in this appendix is described with its reasoning in Section 3.

A.1 Ultrasonic sensors

FRONT SENSOR | LEFT SENSOR | RIGHT SENSOR
VCC → 5 V (buck) | VCC → 5 V (buck) | VCC → 5 V (buck)
GND → common ground | GND → common ground | GND → common ground
TRIG → ESP32 GPIO 13 | TRIG → ESP32 GPIO 14 | TRIG → ESP32 GPIO 25
ECHO → divider → GPIO 34 | ECHO → divider → GPIO 35 | ECHO → divider → GPIO 32
Each divider: ECHO → 1 kΩ → tap to the ESP32 GPIO → 2 kΩ → GND. Never connect a 5 V ECHO line directly to a GPIO.

A.2 Servo

Buck +5 V | → Servo VCC
Buck GND | → Servo GND
ESP32 GPIO → Servo SIGNAL | (record the GPIO used)

A.3 Motor driver and BO motor

ESP32 GPIO 18 → IN1
ESP32 GPIO 19 → IN2
ESP32 GPIO 15 → ENA / PWM
ESP32 GND | → Driver GND
9 V battery | → Driver motor-power input
Driver OUT1 | → BO motor terminal 1
Driver OUT2 | → BO motor terminal 2

A.4 Power and ground

### 9 V battery ──┐

├─→ Motor driver motor-supply input └─→ Buck converter (9 V → 5 V)
├─→ Servo VCC
├─→ Ultrasonic VCC × 3
└─→ ESP32 5 V / VIN (verify the board first)

Common ground: battery · motor driver · buck · ESP32 · servo · ultrasonic

Page 32

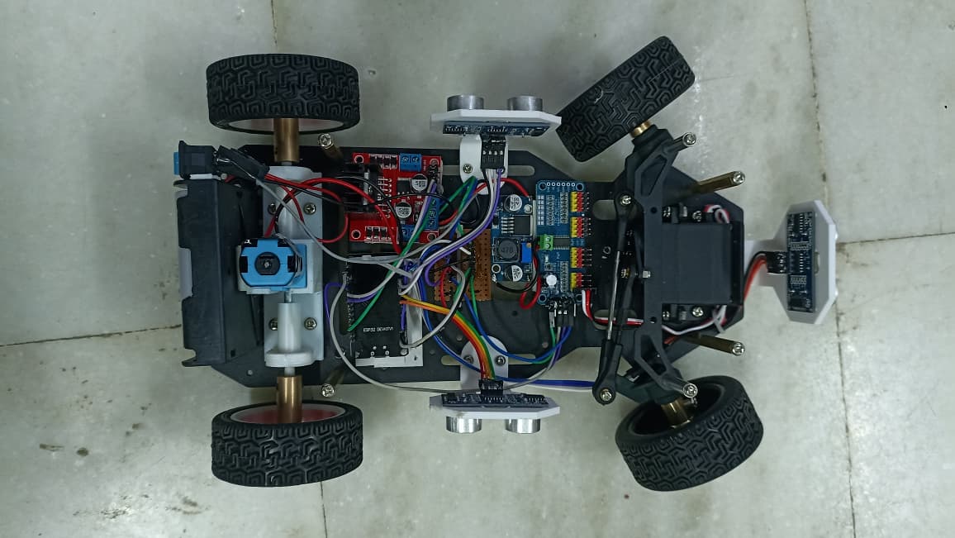
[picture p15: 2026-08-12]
media/images/BOT-TOP-VIEW.jpg

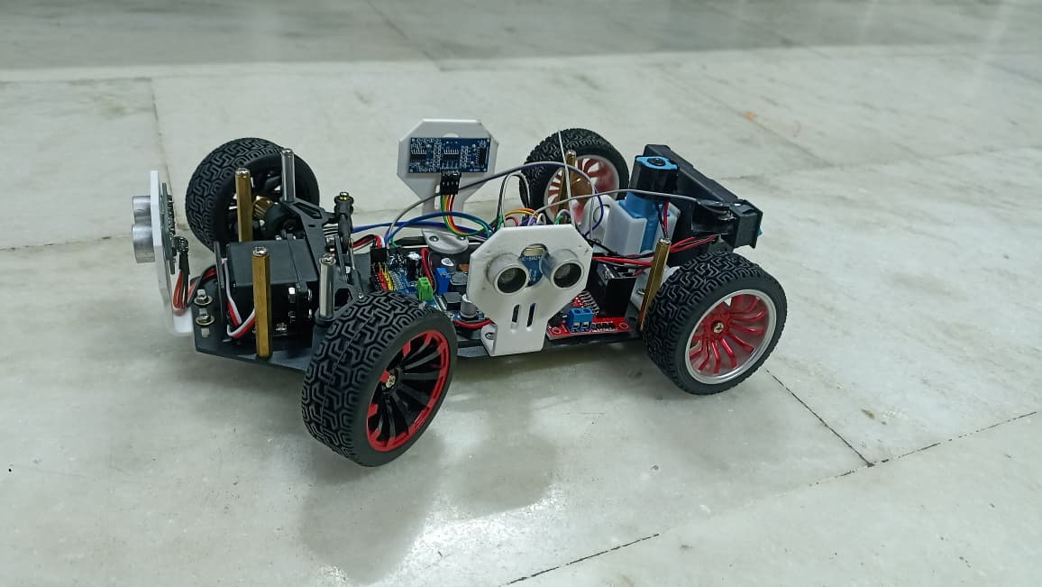
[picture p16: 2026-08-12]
media/images/BOT-LEFT-SIDE.jpg

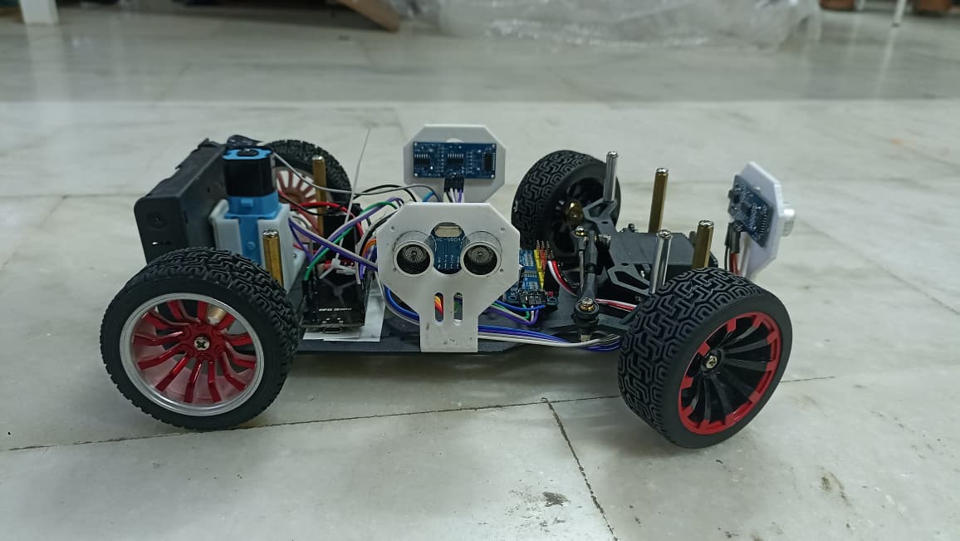
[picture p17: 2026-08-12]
media/images/BOT-RIGHT-SIDE.jpg

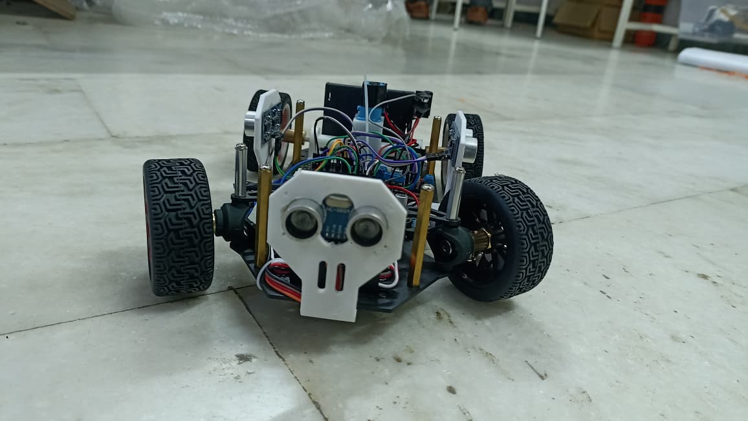
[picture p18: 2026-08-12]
media/images/BOT-FRONT-SIDE.jpg

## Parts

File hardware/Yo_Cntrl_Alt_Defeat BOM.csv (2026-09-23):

Item | Component | Description | Quantity
1 | HUSKYLENS AI Camera | AI machine vision camera sensor for object recognition, face recognition, and tracking | 1
2 | ESP32 DevKit V1 | Wi-Fi and Bluetooth-enabled microcontroller development board | 1
3 | Time-of-Flight (ToF) Sensor (e.g., VL53L0X) | Laser-based distance ranging sensor for obstacle detection | 3
4 | JGB37-520 DC Geared Motor 120 RPM | High-torque DC gear motor with metal gearbox | 1
5 | Quadrature Motor Encoder | Feedback sensor to measure motor speed and rotational position | 1
6 | Robotics Wheels / Tyres | Rubber wheels for mobile robot chassis | 4
7 | BNN055 / BNO085 IMU Sensor | 9-axis Inertial Measurement Unit for orientation and motion tracking | 1
8 | Mechanical Differential | Gear assembly to distribute torque between wheels while allowing different speeds | 1
9 | Drive Shaft / Axle | Metal shafts connecting the motor/differential to the wheels | 2
10 | Custom Acrylic Base Chassis | Laser-cut structural mounting plate for robot components | N.A.
11 | Jumper Wires & Power Cables | Electrical wiring for power distribution and signal connections | N.A.
12 | WS2812B NeoPixel Ring 16 LED | Addressable RGB LED indicator ring | 1
13 | 12V LiPo Battery | Rechargeable Lithium Polymer power source | 1
14 | RoboKit 20kg High Torque Servo Motor | Digital servo motor for steering or actuation mechanisms | 1
15 | 7 Semi Vikram Motor Driver | Dual/multi-channel DC motor driver board | 1

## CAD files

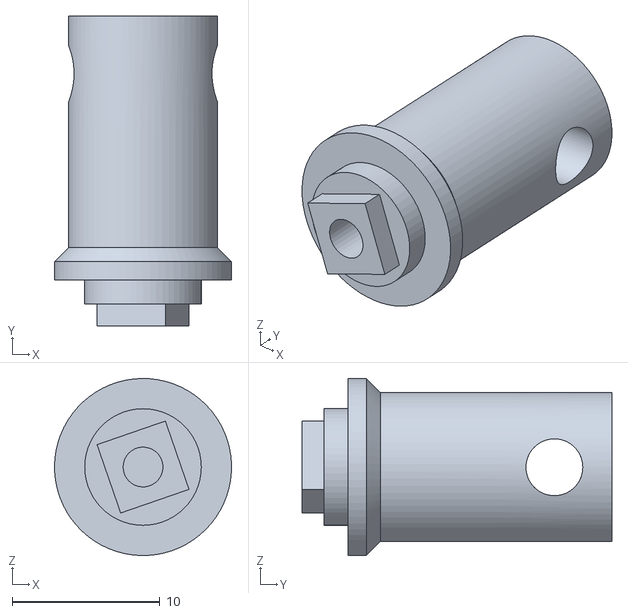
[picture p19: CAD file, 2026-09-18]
hardware/STL_V2/V3 Differential Front & Rear Differential Assy.B.stl
12.0 x 21.0 x 12.0

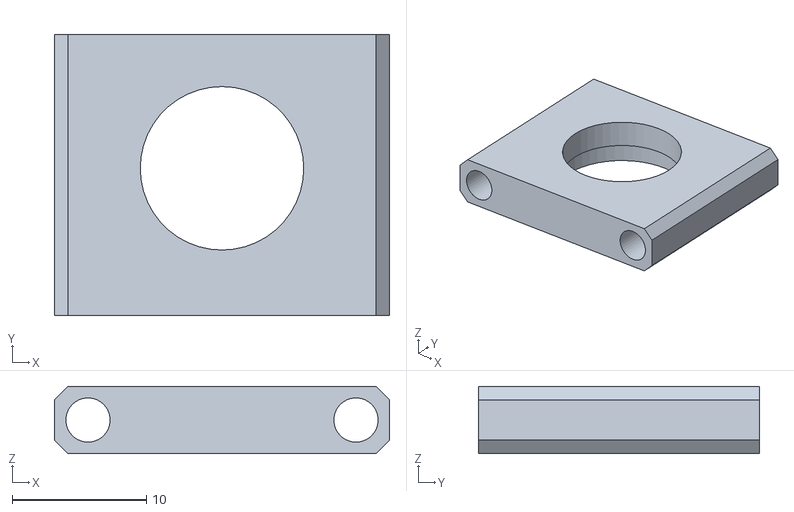
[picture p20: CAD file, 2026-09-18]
hardware/STL_V2/front bearing_6_12_holder.STL
25.0 x 21.0 x 5.00

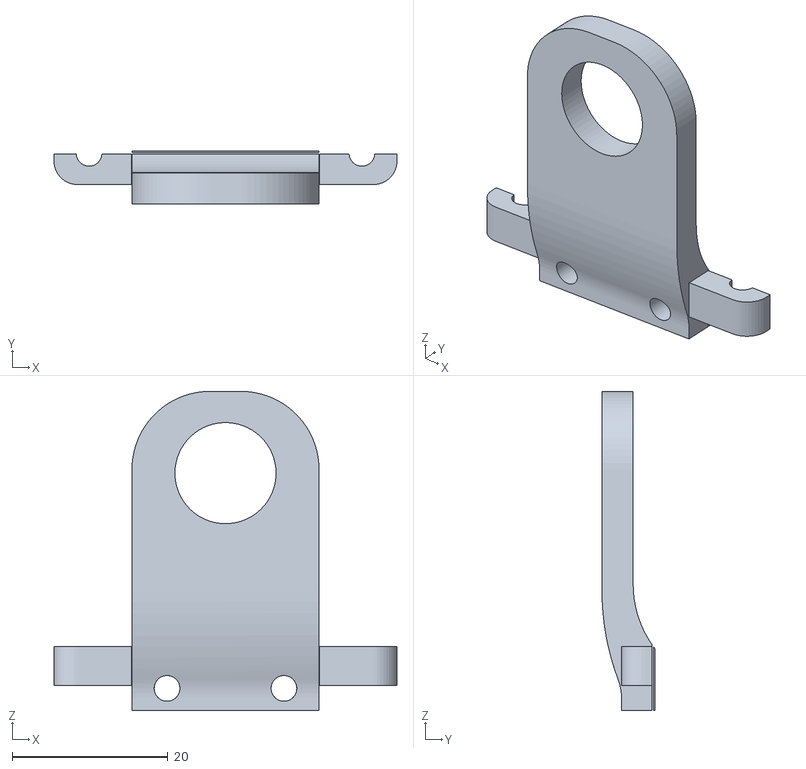
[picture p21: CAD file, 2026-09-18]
hardware/STL_V2/V3 differantial Split.stl
44.0 x 6.80 x 41.0

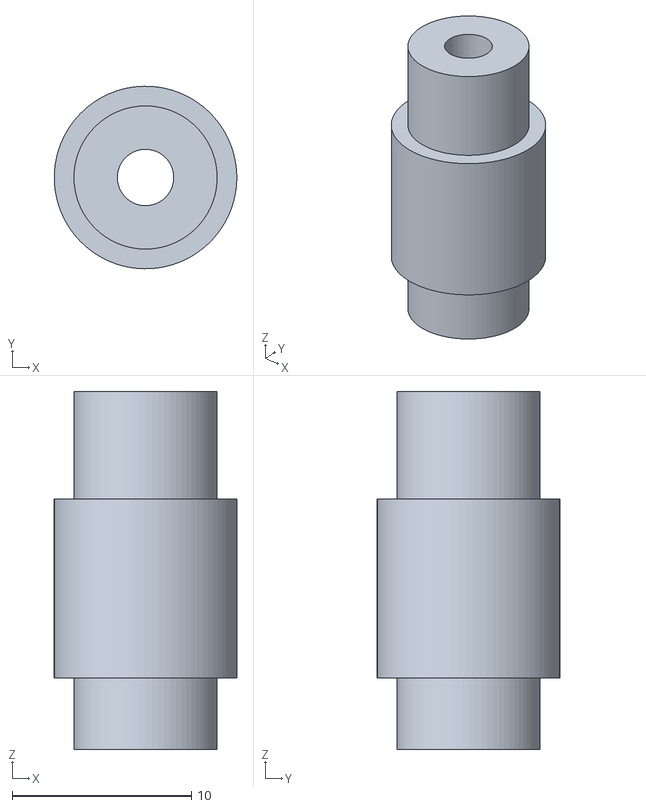
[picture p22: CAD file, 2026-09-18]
hardware/STL_V2/2 Pc V2 coupler for stering FE.stl
10.2 x 10.2 x 20.0

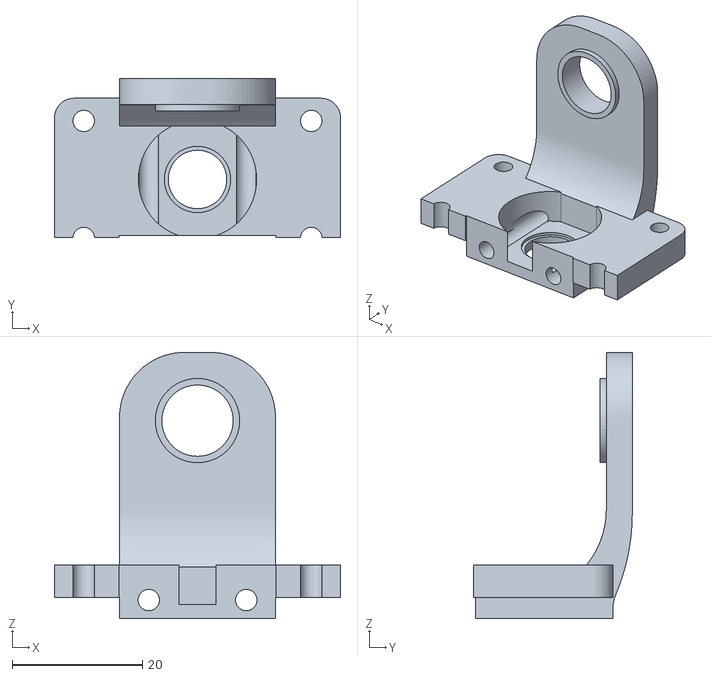
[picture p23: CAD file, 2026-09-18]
hardware/STL_V2/V5 For metal diff differantial setup Holder.stl
44.0 x 24.4 x 41.0

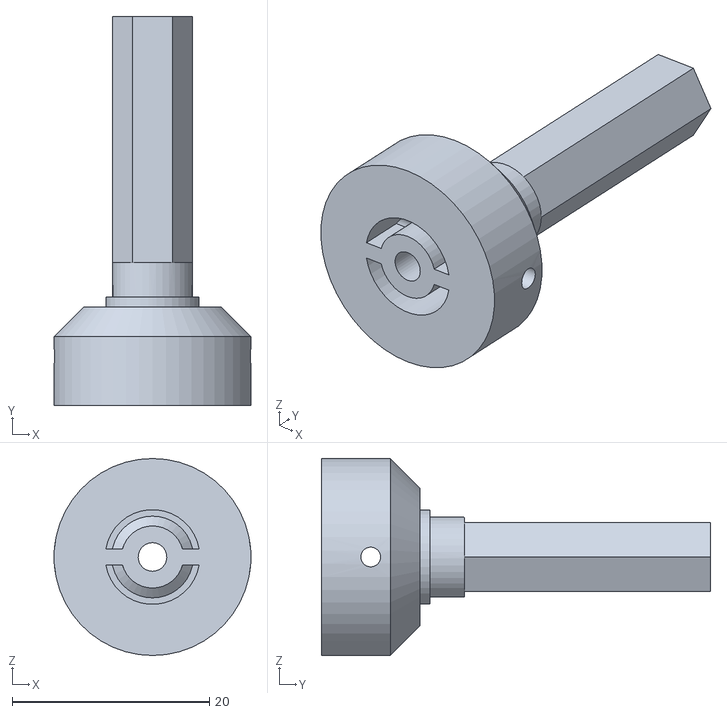
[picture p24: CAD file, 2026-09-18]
hardware/STL_V2/back wheel.STL
20.0 x 39.5 x 20.0

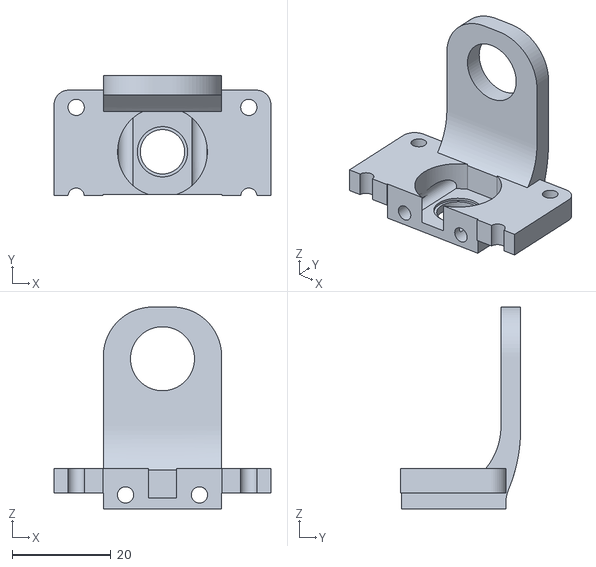
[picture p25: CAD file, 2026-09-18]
hardware/STL_V2/V 4 differantial setup Holder.stl
44.0 x 24.4 x 41.0

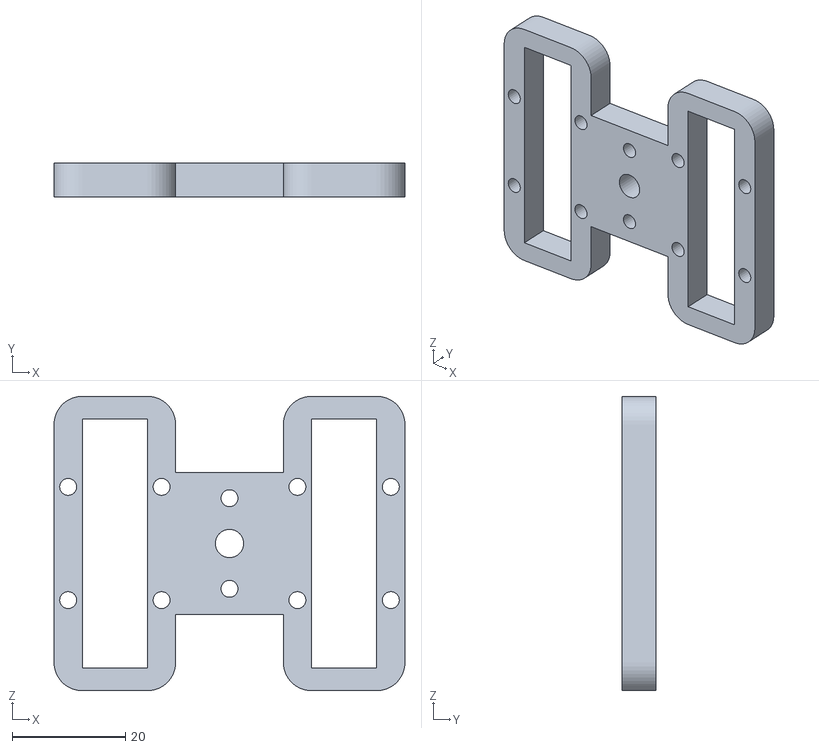
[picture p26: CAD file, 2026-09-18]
hardware/STL_V2/aapoly_6mm_1pc_front axel support.stl
62.0 x 6.00 x 52.0

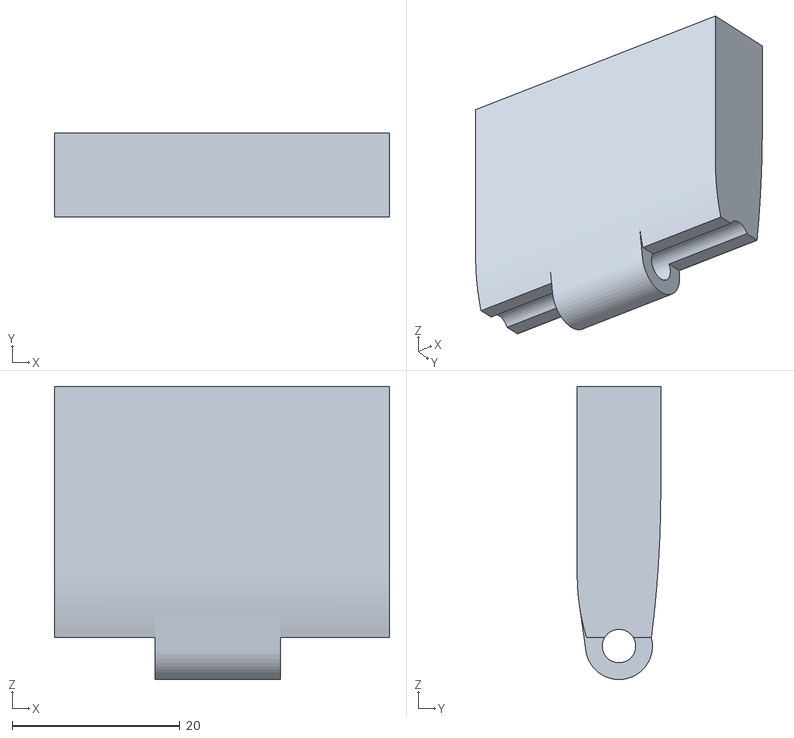
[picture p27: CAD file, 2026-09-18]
hardware/STL_V2/Camera Mount For FE.stl
40.0 x 10.0 x 35.0

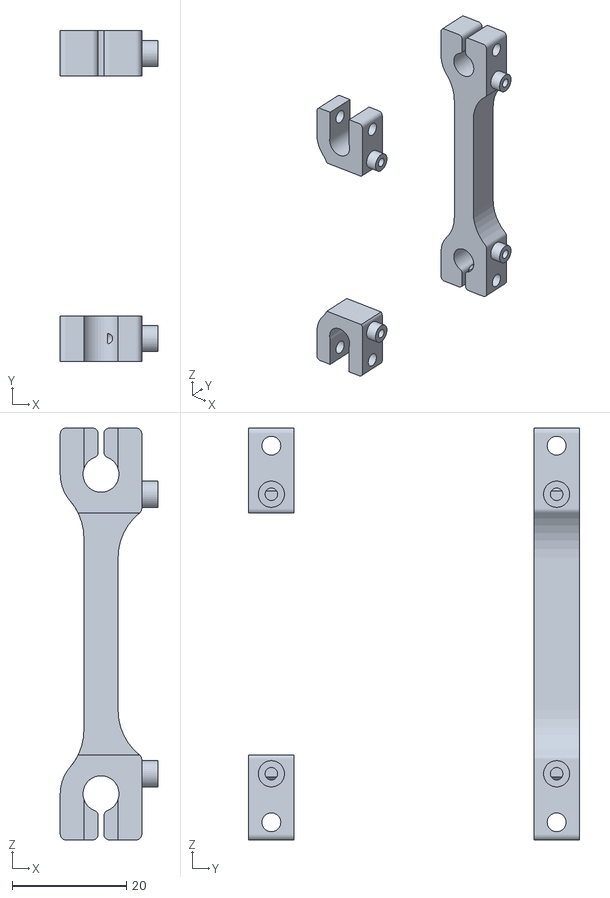
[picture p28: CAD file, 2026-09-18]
hardware/STL_V2/back rpi mount.STL
17.1 x 58.0 x 72.2

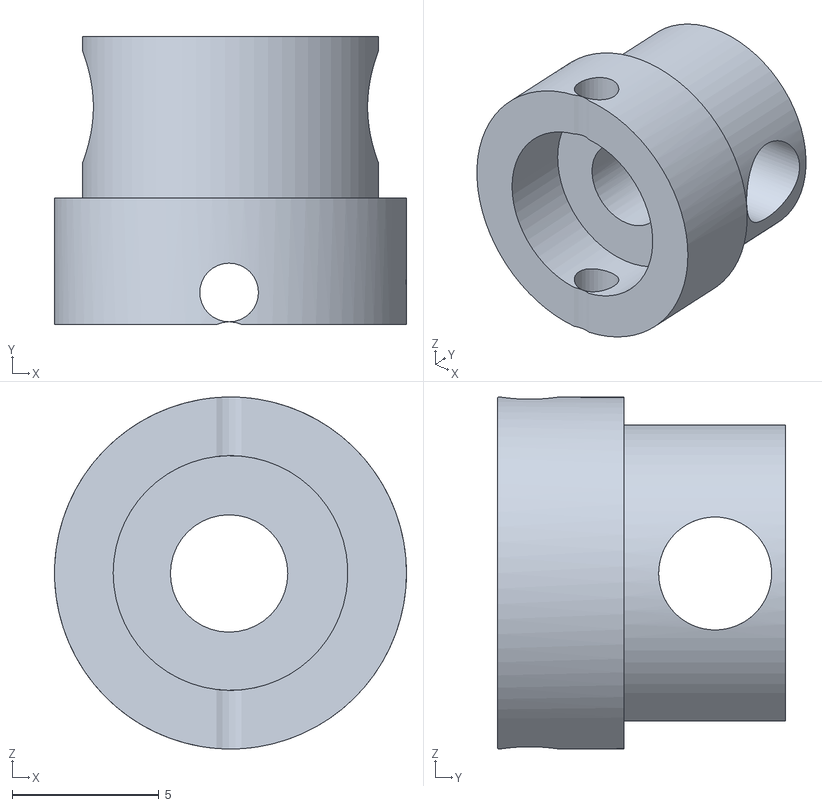
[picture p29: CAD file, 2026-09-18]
hardware/STL_V2/V2 Diff Coupler for carbon rod.stl
12.0 x 9.82 x 12.0

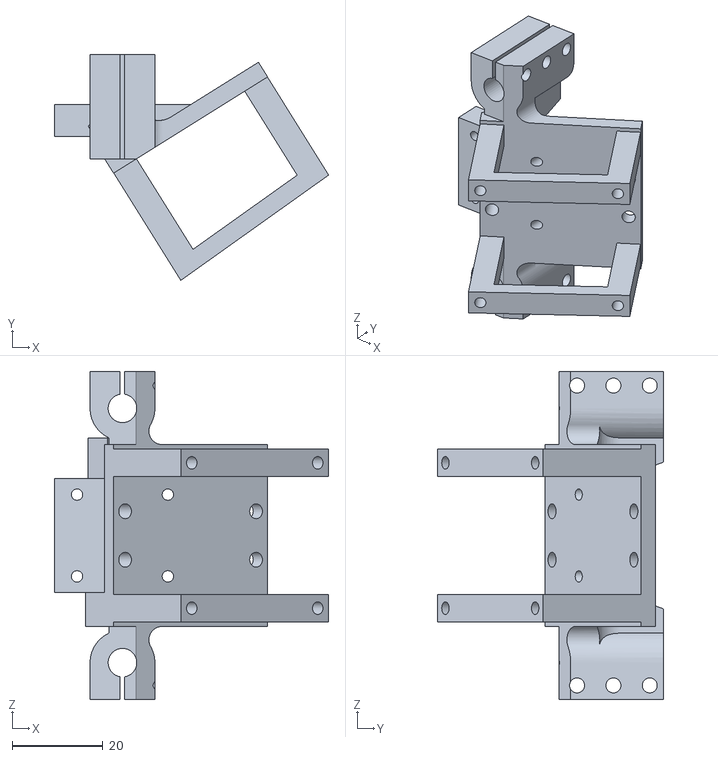
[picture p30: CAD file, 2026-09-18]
hardware/STL_V2/top camera mount.STL
60.4 x 49.7 x 72.2

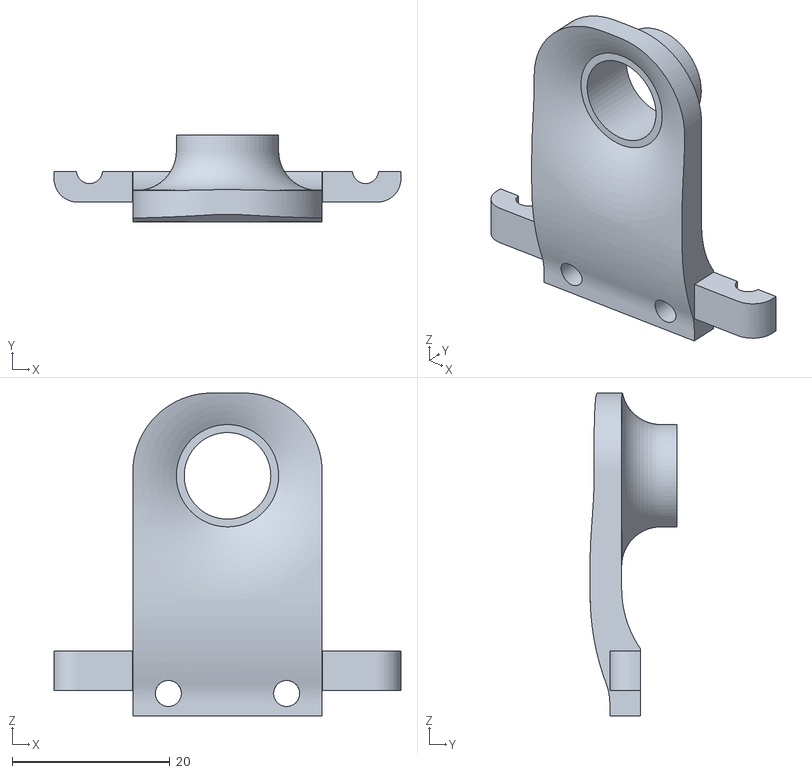
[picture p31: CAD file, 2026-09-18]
hardware/STL_V2/V5 Split for Metal differantial setup Holder.stl
44.0 x 11.0 x 41.0

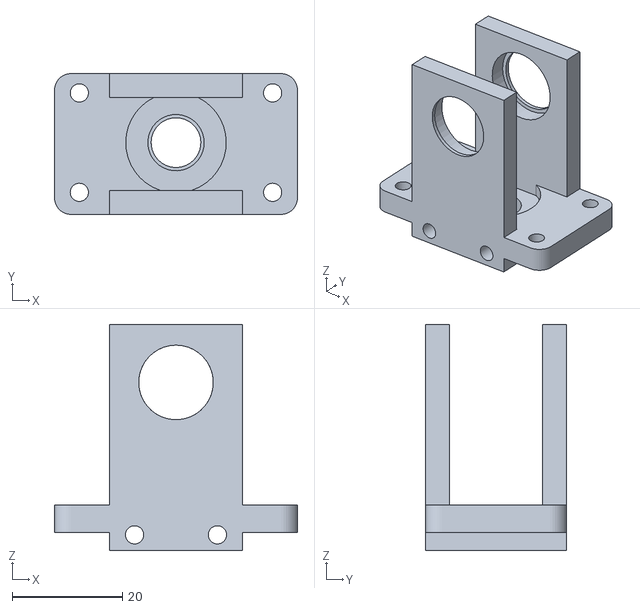
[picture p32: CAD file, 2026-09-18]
hardware/STL_V2/back Gear Mount.STL
44.0 x 25.5 x 41.0

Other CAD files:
hardware/STL_V2/2 pcs Diff Coupler for carbon rod.stl
hardware/STL_V2/coupler for stering FE.stl
hardware/STL_V2/dc motor mount.STL
hardware/STL_V2/V3 differantial setup Holder part 2.stl
hardware/STL_V2/Diff Coupler for carbon rod for metal diff.stl
hardware/STL_V2/FE Error 404 Camera mount.stl
hardware/STL_V2/Front wheel.STL
hardware/STL_V2/Turning FE V1.stl
hardware/STL_V2/V2 Motor mount for FE.stl
hardware/STL_V2/V2 differantial setup Holder.stl
hardware/STL_V2/aachassis body_6mm poly_1pc.stl
hardware/STL_V2/aaside bearing mount_ 3mm AL_ 2pc.stl
hardware/STL_V2/dc motor coupling.STL
hardware/STL_V2/metal diff coupler V1.stl
hardware/STL_V2/new front wheel.STL
hardware/STL_V2/side bearing plate mount.STL
hardware/STL_V2/side mount tf mini mount.STL

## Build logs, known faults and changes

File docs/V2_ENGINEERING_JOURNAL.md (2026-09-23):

# YO_ERROR-404 Future Engineers V2 engineering journal

## Document purpose

This document records the proposed Version 2 of the YO_ERROR-404 Future Engineers robot. It is a build and test record, not a claim of final competition performance. Measurements, component ratings and run results must be recorded during validation before being presented as achieved results.

Version 2 keeps the useful principle of the existing robot: a Raspberry Pi performs high-level vision while an ESP32 handles time-critical sensing and actuation. V2 changes the mechanical platform and makes the power, sensing and test process more deliberate.

| Journal section | Evidence to add before final submission |
| --- | --- |
| Robot views | Front-left, top, right-side, wiring and underside photographs |
| Mechanical design | Chosen STL revision, material, print settings and dry-fit record |
| Electrical design | Wiring diagram, power measurements and current test record |
| Software design | Command protocol, calibration file and tested source revision |
| Validation | Dated run log with failures, corrections and repeat results |

## Image evidence

> **V2 complete robot**<br>


> **IV2 top view**<br>


> **IV2 power and wiring view**<br>


## Why move from V1 to V2

The existing repository describes a compact prototype using a BO motor, HC-SR04 ultrasonic sensors, a 9 V supply and a basic front-steering chassis. That platform is useful for early software work, but it limits repeatability on a WRO field.

V2 is intended to solve the following problems:

| V1 limitation | V2 response | Expected benefit |
| --- | --- | --- |
| BO motor and light drivetrain | 12 V geared motor with quadrature encoder and differential drivetrain | More repeatable speed and distance control |
| Ultrasonic sensors have a broad acoustic cone | Four short-range ToF sensors on a TCA9548A I2C multiplexer | More precise wall-distance data at the required sensor positions |
| Small chassis has limited mounting rigidity | 6 mm polycarbonate chassis with printed PETG mounts and bearing supports | Better alignment, easier servicing and less vibration |
| One general power path | Separate motor, servo and logic power domains with a common ground | Lower risk of controller reset during motor or servo load |
| Open-loop driving adjustments | Encoder, IMU, ToF and camera data used as feedback | Better recovery from drift and course variation |

## V2 design goals

- Fit within the current WRO Future Engineers size and safety rules. Confirm the official rulebook before final fabrication.
- Keep the centre of gravity low and keep steering, drivetrain and sensing mounts serviceable.
- Measure distance and heading rather than relying only on time-based movement.
- Build in stages so each subsystem can be tested alone before full-course testing.
- Store source code, calibration values, wiring photographs and STL revisions together.

## System architecture

```mermaid
flowchart LR
    Camera[Pi camera] --> Pi[Raspberry Pi\nVision and mission logic]
    Pi <-->|Serial heartbeat and commands| ESP[ESP32-C3\nReal-time control]
    ESP --> IMU[IMU]
    ESP --> Mux[TCA9548A I2C multiplexer]
    Mux --> ToF[Four ToF sensor channels]
    ESP --> Servo[Steering servo]
    ESP --> Driver[Motor driver]
    Driver --> Motor[12 V geared motor]
    Motor --> Encoder[Quadrature encoder]
    Encoder --> ESP
```

The Raspberry Pi owns image capture, colour/obstacle interpretation and the high-level state machine. The ESP32-C3 owns sensor polling, encoder counting, PWM output, safe-stop behaviour and serial telemetry. The two controllers must share a documented command protocol and a common electrical ground.

## Control-loop flow

```mermaid
flowchart TD
    Start[Power on] --> Health[Check sensor health, serial link and battery]
    Health -->|Fault| Stop[Stop motor and report fault]
    Health -->|Ready| Wait[Wait for start command]
    Wait --> Read[Read vision, ToF, IMU and encoder]
    Read --> Plan[Select mission state and target path]
    Plan --> Control[Compute steering and motor command]
    Control --> Execute[ESP32 applies outputs]
    Execute --> Telemetry[Log telemetry and run state]
    Telemetry --> Finished{Mission complete?}
    Finished -->|No| Read
    Finished -->|Yes| Stop
```

## Mechanical design

### Chassis and steering

The local V2 manufacturing library contains a 6 mm chassis body, front-axle support, side-bearing mounts, steering couplers, camera mounts and differential supports. These parts support a rear differential drivetrain and servo-actuated front steering.

Print structural mounts in PETG, not PLA, when they carry motor, steering, bearing or camera loads. PETG provides better heat resistance and layer adhesion during repeated vibration testing. Use heat-set inserts or locknuts where a screw must be removed repeatedly.

Before printing a final set, check the following against the physical parts:

- motor body length, shaft diameter and coupling engagement;
- differential holder and bearing fit;
- steering travel without wheel or chassis interference;
- camera and sensor field of view;
- encoder clearance and cable bend radius.

### STL release

The `hardware/STL_V2/` folder contains the 31 root-level STL files supplied for this V2 release. It intentionally excludes STEP, STP, DXF, 3MF, F3D and image files. Several filenames describe older or alternate iterations; treat them as a fabrication library, not proof that every file belongs in the final assembly.

The final build should have a short bill of materials that maps each fitted component to one STL filename, material, infill, nozzle size and tested revision.

## Electrical and power architecture

| Domain | Proposed supply | Loads | Verification before integration |
| --- | --- | --- | --- |
| Motor | 12 V battery rail | Geared motor and motor driver | Measure free-run, loaded and brief stall-current limits |
| Servo | Dedicated regulated rail within the servo rating | Steering servo | Confirm voltage under full steering load |
| Logic | Regulated 5 V rail | Raspberry Pi and ESP32-C3 VIN/USB | Confirm no brownout when motor and servo operate |
| Sensors | Clean 3.3 V rail | ToF sensors, multiplexer and IMU | Confirm voltage and I2C stability under PWM noise |

All domains require a common ground at a planned star point. Route motor and servo current away from the IMU and I2C wiring. Use a main fuse, a physical power switch and strain relief on battery wires.

### Motor-driver decision

The intended 900 RPM Johnson motor with encoder must be matched to a motor driver using measured current, not nominal voltage alone. The Vikram-453R6 is rated below the motor listing's maximum load-current value, so it must not be accepted for V2 until current limiting and real drivetrain current have been verified. A driver with enough continuous-current margin, such as a 10 A-class option, is the safer initial test choice.

## Sensing and control

### ToF array

Four identical VL53L0X-style sensors start at the same I2C address. V2 uses a TCA9548A multiplexer so the ESP32 can isolate each sensor channel. During bench testing, record readings at known distances and save per-sensor offsets in configuration.

Place sensors only after verifying that the surrounding mount does not block their field of view. If the field environment shows unreliable close-range readings, retain an alternative mount for a single side-facing TFmini-style sensor rather than changing the full design at the event.

### Motion feedback

The quadrature encoder provides wheel-speed and distance feedback. The IMU provides heading feedback. Use the encoder to avoid timing-only distance estimates, and use the IMU to detect accumulated heading error. Calibration values must be kept in a versioned configuration file, not buried in code.

### Software responsibilities

| Raspberry Pi | ESP32-C3 |
| --- | --- |
| Camera capture and image processing | ToF, IMU and encoder polling |
| Open/Obstacle round state machine | Motor PWM, direction and steering PWM |
| High-level target selection | Low-level safety stop and telemetry |
| Log run outcome and visual confidence | Report distances, heading, counts and faults |

The serial protocol should include a heartbeat, an explicit STOP command and a defined response when communication is stale. The ESP32 must stop propulsion on sensor failure, stale command input or an explicit stop request.

## Version 2 advantages

1. A more rigid differential platform improves repeatability of steering and wheel alignment.
2. Encoder feedback gives a measurable basis for speed and distance calibration.
3. Four ToF channels provide coverage at front, left, right and rear locations when the mounts are validated.
4. Separating motor, servo and logic power reduces reset and noise risk.
5. The STL-only release makes fabrication accessible without exposing editable CAD source files.
6. The Pi-plus-ESP32 split keeps image work away from real-time motor and sensor tasks.

## Learnings carried from V1

- Test one hardware subsystem at a time before joining it to the full robot.
- Mechanical alignment and cable routing affect reliability as much as code does.
- A sensor reading is only useful after mounting, lighting and field conditions have been tested.
- Calibrations must be written down and backed up after every successful run.
- Avoid a large code or hardware change immediately before a competition run.
- Keep a safe-stop path independent of the high-level vision process.

## Validation plan

| Stage | Test | Acceptance evidence |
| --- | --- | --- |
| Mechanical | Roll test, steering sweep and coupling inspection | No binding, rub or loose fasteners |
| Power | Motor/servo load test with logic rail monitored | No reset or unsafe heat |
| Sensors | ToF readings at known distances and IMU heading check | Saved offsets and repeatable readings |
| Drive | Straight 1 m runs and repeated turns | Logged distance and heading error |
| Vision | Red/green object tests under the event lighting | Saved frames and confidence observations |
| Full system | Repeated Open and Obstacle round practice | Run log, failure reason and targeted fix |

## Release contents

- `hardware/STL_V2/`: STL fabrication library supplied for V2.
- `hardware/ELECTRONICS_V2/`: component architecture, integration rules and electrical bench-test worksheet.
- `src/`: existing ESP32 and Raspberry Pi code snapshots. These require pin, protocol and calibration updates before being treated as V2-final firmware.
- `docs/V2_ENGINEERING_JOURNAL.md`: V2 design basis, risks and validation plan.

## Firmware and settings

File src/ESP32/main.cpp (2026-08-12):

#include <Wire.h>
#include <MPU6050_tockn.h>
#include <ESP32Servo.h>
#include <WiFi.h>
#include <WiFiClient.h>
#include <WiFiServer.h>

// ==== PIN Definitions ====
#define BUTTON_PIN 23  // Start button input

#define IN1 13
#define IN2 14
#define ENA 26

#define SERVO_PIN 27
#define SERVO_LEFT 55
#define SERVO_RIGHT 132
#define SERVO_STRAIGHT 92

// Front Ultrasonic
#define TRIG_FRONT 16
#define ECHO_FRONT 18

// Right Ultrasonic
#define TRIG_RIGHT 19
#define ECHO_RIGHT 33

// ==== Global Variables ====
MPU6050 mpu6050(Wire);
Servo steeringservo;

// ==== Navigation tuning ====
const int DRIVE_SPEED = 150;
const int REVERSE_SPEED = 120;
const float FRONT_STOP_CM = 25.0;
const float RIGHT_OPEN_CM = 90.0;
const float RIGHT_TURN_FRONT_CM = 75.0;
const float LEFT_TURN_FRONT_CM = 70.0;
const float RIGHT_TURN_TARGET_DEG = 117.0;
const float LEFT_TURN_TARGET_DEG = 133.0;

unsigned long lastStatusLog = 0;
const unsigned long STATUS_LOG_INTERVAL = 250;

// Lap counting variables
int turn_count = 0;        // Count of 90-degree turns made
int lap_count = 0;         // Number of laps completed
int turns_per_lap = 4;     // Assume 4 turns per lap initially (will be auto-detected)
bool first_lap = true;     // Flag to detect first lap completion

// Starting position detection
float starting_front_distance = 0;  // Store front distance at start
bool starting_position_recorded = false;
bool returning_to_start = false;    // Flag when looking for starting position

// IMU drift compensation
float yawOffset = 0;
unsigned long lastDriftReset = 0;
const unsigned long DRIFT_RESET_INTERVAL = 30000; // Reset drift every 30 seconds

// ==== WiFi Credentials ====
const char* ssid = "Airtel_yolabs_apr";
const char* password = "yolabs4321";

// ==== Telnet Server ====
WiFiServer telnetServer(23);
WiFiClient telnetClient;

// ==== Setup Telnet Logging ====
void setupWiFiTelnet() {
  WiFi.begin(ssid, password);
  Serial.print("Connecting to WiFi");
  while (WiFi.status() != WL_CONNECTED) {
    delay(500);
    Serial.print(".");
  }
  Serial.println("\nWiFi connected!");
  Serial.print("IP Address: ");
  Serial.println(WiFi.localIP());

  telnetServer.begin();
  telnetServer.setNoDelay(true);
  Serial.println("Telnet server started");
}

// ==== Handle Telnet Clients (place in loop) ====
void handleTelnetClient() {
  if (telnetServer.hasClient()) {
    if (!telnetClient || !telnetClient.connected()) {
      if (telnetClient) telnetClient.stop();
      telnetClient = telnetServer.available();
      Serial.println("New Telnet client connected");
      telnetClient.println("Welcome to ESP32 Telnet Server");
    } else {
      telnetServer.available().stop();  // Reject multiple clients
    }
  }
}

// ==== Logging Function ====
void logPrint(String msg) {
  Serial.println(msg);
  if (telnetClient && telnetClient.connected()) {
    telnetClient.println(msg);
  }
}

float readUltrasonicDistance(int trigPin, int echoPin) {
  digitalWrite(trigPin, LOW);
  delayMicroseconds(2);
  digitalWrite(trigPin, HIGH);
  delayMicroseconds(10);
  digitalWrite(trigPin, LOW);
  
  long duration = pulseIn(echoPin, HIGH, 30000); // Wait for echo, timeout after 30ms
  if (duration == 0) return 999.0; // Return max distance if no echo
  
  float distance = duration * 0.034 / 2.0; // Convert to cm
  return (distance > 0 && distance < 400) ? distance : 999.0; // Valid range
}

// Get compensated yaw angle with drift correction
float getCompensatedYaw() {
  // Reset drift compensation every 30 seconds when robot is stationary
  if (millis() - lastDriftReset > DRIFT_RESET_INTERVAL) {
    // Only reset if we're going relatively straight (no major turns recently)
    float currentYaw = mpu6050.getAngleZ();
    if (abs(currentYaw - yawOffset) < 5.0) { // If drift is small, reset
      yawOffset = currentYaw;
      lastDriftReset = millis();
      Serial.println("Yaw drift reset");
    }
  }
  
  return mpu6050.getAngleZ() - yawOffset;
}

void setMotor(bool forward, int speed) {
  speed = constrain(speed, 0, 255);

  if (forward) {
    digitalWrite(IN1, LOW);
    digitalWrite(IN2, HIGH);
  } else {
    digitalWrite(IN1, HIGH);
    digitalWrite(IN2, LOW);
  }

  analogWrite(ENA, speed);
}

void driveForward(int speed) {
  setMotor(true, speed);
}

void driveBackward(int speed) {
  setMotor(false, speed);
}

void stopMotors() {
  digitalWrite(IN1, HIGH);
  digitalWrite(IN2, HIGH);
  analogWrite(ENA, 0);
}

void straightenSteering() {
  steeringservo.write(SERVO_STRAIGHT);
}

void moveBackwardToSafeDistance() {
  Serial.println("Too close! Moving backward to safe distance...");
  
  float frontDist;
  do {
    driveBackward(REVERSE_SPEED); // Slow backward movement
    delay(100);
    
    // Read front distance
    frontDist = readUltrasonicDistance(TRIG_FRONT, ECHO_FRONT);
    Serial.print("Moving back... Front distance: ");
    Serial.println(frontDist);
    
  } while (frontDist < 40 && frontDist != 999.0); // Continue until 40-50cm range
  
  stopMotors();
  delay(200);
  Serial.println("Safe distance reached!");
}

void turnLeft() {
  steeringservo.write(SERVO_LEFT);
  driveForward(DRIVE_SPEED); // Adjust speed as needed
  delay(500); // Allow time for the servo to turn
}

void turnRight90Degrees() {
  Serial.println("=== STARTING RIGHT TURN ===");
  //stopMotors();
  //delay(200); // Brief stop before turning
  
  // Test servo before starting turn
  Serial.println("Testing servo movement...");
  steeringservo.write(SERVO_RIGHT);
  Serial.print("Servo commanded to: ");
  Serial.println(SERVO_RIGHT);
  delay(500); // Give servo time to move
  
  // Initialize angle change tracking
  mpu6050.update();
  float startYaw = getCompensatedYaw();
  float angleChanged = 0;
  float lastYaw = startYaw;
  
  Serial.print("Starting relative turn from: ");
  Serial.print(startYaw, 1);
  Serial.println("°");
  
  // Turn right with steering and drive forward
  driveForward(DRIVE_SPEED); // Slower speed for more precise turning
  Serial.println("Driving forward while turning...");
  
  unsigned long turnStartTime = millis();
  const unsigned long MAX_TURN_TIME = 10000; // Maximum 10 seconds for safety

  // Keep turning until we've changed 85-90 degrees (account for some error)
  while (millis() - turnStartTime < MAX_TURN_TIME && abs(angleChanged) < RIGHT_TURN_TARGET_DEG) {
    mpu6050.update();
    float currentYaw = getCompensatedYaw();
    
    // Calculate the change in angle from last reading
    float deltaAngle = currentYaw - lastYaw;
    
    // Handle angle wrapping for delta calculation
    if (deltaAngle > 180) {
      deltaAngle -= 360;
    } else if (deltaAngle < -180) {
      deltaAngle += 360;
    }
    
    // Accumulate the angle change
    angleChanged += deltaAngle;
    lastYaw = currentYaw;
    
    // Print progress at a controlled interval
    static unsigned long lastTurnLog = 0;
    if (millis() - lastTurnLog >= 200) {
      lastTurnLog = millis();
      Serial.print("Angle changed: ");
      Serial.print(angleChanged, 1);
      Serial.print("° (Current: ");
      Serial.print(currentYaw, 1);
      Serial.println("°)");
    }
    
    delay(20); // Small delay for stability
  }
  
  // Stop and straighten steering
  Serial.println("Stopping motors and straightening servo...");
  Serial.print("Total angle changed: ");
  Serial.print(angleChanged, 1);
  Serial.println("°");
  
  //stopMotors();
  //delay(200);
  straightenSteering();
  Serial.print("Servo commanded to straight: ");
  Serial.println(SERVO_STRAIGHT);
  delay(300);
  
  // Increment turn counter for lap tracking
  turn_count++;
  Serial.print("Turn completed! Total turns: ");
  Serial.print(turn_count);
  
  // Check for lap completion
  if (first_lap) {
    // For first lap, we don't know how many turns per lap yet
    Serial.print(" (First lap in progress)");
  } else {
    Serial.print(" (Lap ");
    Serial.print(lap_count + 1);
    Serial.print(" in progress)");
  }
  Serial.println();
  
  Serial.println("=== Relative angle turn completed ===");
}


void leftTurn() {
  Serial.println("=== STARTING LEFT TURN ===");
  //stopMotors();
  //delay(200); // Brief stop before turning
  
  // Test servo before starting turn
  Serial.println("Testing servo movement...");
  steeringservo.write(SERVO_LEFT);
  Serial.print("Servo commanded to: ");
  Serial.println(SERVO_LEFT);
  delay(500); // Give servo time to move
  
  // Initialize angle change tracking
  mpu6050.update();
  float startYaw = getCompensatedYaw();
  float angleChanged = 0;
  float lastYaw = startYaw;
  
  Serial.print("Starting relative turn from: ");
  Serial.print(startYaw, 1);
  Serial.println("°");
  
  // Turn right with steering and drive forward
  driveForward(DRIVE_SPEED); // Slower speed for more precise turning
  Serial.println("Driving forward while turning...");
  
  unsigned long turnStartTime = millis();
  const unsigned long MAX_TURN_TIME = 10000; // Maximum 10 seconds for safety

  // Keep turning until we've changed 85-90 degrees (account for some error)
  while (millis() - turnStartTime < MAX_TURN_TIME && abs(angleChanged) < LEFT_TURN_TARGET_DEG) {
    mpu6050.update();
    float currentYaw = getCompensatedYaw();
    
    // Calculate the change in angle from last reading
    float deltaAngle = currentYaw - lastYaw;
    
    // Handle angle wrapping for delta calculation
    if (deltaAngle > 180) {
      deltaAngle -= 360;
    } else if (deltaAngle < -180) {
      deltaAngle += 360;
    }
    
    // Accumulate the angle change
    angleChanged += deltaAngle;
    lastYaw = currentYaw;
    
    // Print progress at a controlled interval
    static unsigned long lastTurnLog = 0;
    if (millis() - lastTurnLog >= 200) {
      lastTurnLog = millis();
      Serial.print("Angle changed: ");
      Serial.print(angleChanged, 1);
      Serial.print("° (Current: ");
      Serial.print(currentYaw, 1);
      Serial.println("°)");
    }
    
    delay(20); // Small delay for stability
  }
  
  // Stop and straighten steering
  Serial.println("Stopping motors and straightening servo...");
  Serial.print("Total angle changed: ");
  Serial.print(angleChanged, 1);
  Serial.println("°");

  //stopMotors();
  //delay(200);
  straightenSteering();
  Serial.print("Servo commanded to straight: ");
  Serial.println(SERVO_STRAIGHT);
  delay(300);
  
  // Increment turn counter for lap tracking
  turn_count++;
  Serial.print("Turn completed! Total turns: ");
  Serial.print(turn_count);
  
  // Check for lap completion
  if (first_lap) {
    // For first lap, we don't know how many turns per lap yet
    Serial.print(" (First lap in progress)");
  } else {
    Serial.print(" (Lap ");
    Serial.print(lap_count + 1);
    Serial.print(" in progress)");
  }
  Serial.println();
  
  Serial.println("=== Relative angle turn completed ===");
}




// testServo() removed for clean autonomous operation

bool isAtStartingPosition(float currentFrontDistance) {
  // Check if current front distance matches starting distance (within 5cm tolerance)
  float tolerance = 5.0; // cm
  return abs(currentFrontDistance - starting_front_distance) <= tolerance;
}

void recordStartingPosition() {
  // Record the starting front distance
  float frontDist = readUltrasonicDistance(TRIG_FRONT, ECHO_FRONT);
  starting_front_distance = frontDist;
  starting_position_recorded = true;
  
  Serial.println("========================");
  Serial.print("STARTING POSITION RECORDED: ");
  Serial.print(starting_front_distance, 1);
  Serial.println("cm from front obstacle");
  Serial.println("========================");
}

// Forward declaration to fix 'not declared in this scope' error
void completeFirstLap();

void checkLapCompletion() {
  // Auto-complete first lap after 4 turns (typical for rectangular track)
  if (first_lap && turn_count >= 4) {
    Serial.println("Auto-detecting first lap completion after 4 turns...");
    Serial.println("Continuing for more laps...");
    completeFirstLap();
    // Don't set returning_to_start here - continue lapping!
    return;
  }
  
  if (first_lap) {
    // Still in first lap, keep counting turns
    return;
  }
  
  // For subsequent laps, check if we've made the required number of turns
  if (turn_count >= (lap_count + 1) * turns_per_lap) {
    lap_count++;
    Serial.println("========================");
    Serial.print("LAP ");
    Serial.print(lap_count);
    Serial.println(" COMPLETED!");
    Serial.print("Total turns so far: ");
    Serial.println(turn_count);
    Serial.println("========================");
    
    // Check if we've completed the target number of laps
    if (lap_count >= 3) { // Complete 3 laps first
      Serial.println("TARGET LAPS COMPLETED! Now returning to starting position...");
      returning_to_start = true; // Start looking for starting position instead of stopping immediately
    }
  }
}
void completeFirstLap() {
  // Call this function when you determine the first lap is complete
  // This sets the turns_per_lap for future lap counting
  if (first_lap) {
    turns_per_lap = turn_count;
    first_lap = false;
    lap_count = 1;
    
    Serial.println("========================");
    Serial.println("FIRST LAP COMPLETED!");
    Serial.print("Detected ");
    Serial.print(turns_per_lap);
    Serial.println(" turns per lap");
    Serial.println("Starting lap counting...");
    Serial.println("========================");
  }
}

void setup() {
  Serial.begin(115200);
  setupWiFiTelnet();

  pinMode(BUTTON_PIN, INPUT_PULLUP);
  pinMode(IN1, OUTPUT);
  pinMode(IN2, OUTPUT);
  pinMode(ENA, OUTPUT);
  pinMode(TRIG_FRONT, OUTPUT);
  pinMode(ECHO_FRONT, INPUT);
  pinMode(TRIG_RIGHT, OUTPUT);
  pinMode(ECHO_RIGHT, INPUT);

  Serial.println("Waiting for button press to start...");
  while (digitalRead(BUTTON_PIN) == HIGH) {
    delay(10);
  }

  Serial.println("Button pressed, starting setup...");

  // Initialize Servo
  steeringservo.attach(SERVO_PIN);
  straightenSteering(); // Set initial position to straight

  Wire.begin(21, 22); // SDA, SCL pins for I2C
  mpu6050.begin();
  
  Serial.println("Calibrating gyroscope... Keep robot STILL!");
  mpu6050.calcGyroOffsets(true); // Calculate gyro offsets - KEEP THIS!
  // DO NOT call mpu6050.setGyroOffsets(0, 0, 0) - it destroys calibration!
  
  Serial.println("IMU calibration complete!");
  delay(1000); // Wait for MPU6050 to stabilize
  
  // Initialize yaw offset for drift compensation
  mpu6050.update();
  yawOffset = mpu6050.getAngleZ();
  lastDriftReset = millis();
  
  // Record starting position after a brief delay
  delay(2000); // Wait 2 seconds for sensors to stabilize
  recordStartingPosition();
}


void loop() {
  // Handle telnet client and update sensors
  handleTelnetClient();
  mpu6050.update();
  
  // Manual control code removed for clean autonomous operation
  
  float yawNow = getCompensatedYaw(); // Use compensated yaw
  float distFront = readUltrasonicDistance(TRIG_FRONT, ECHO_FRONT);
  float distRight = readUltrasonicDistance(TRIG_RIGHT, ECHO_RIGHT);

  // Log sensor data for debugging
  String statusMsg = "Yaw:" + String(yawNow, 1) + ", Front:" + String(distFront, 1) + ", Right:" + String(distRight, 1) + 
           ", Turns:" + String(turn_count) + ", Laps:" + String(lap_count);
  
  if (returning_to_start) {
    statusMsg += ", RETURNING TO START (Target: " + String(starting_front_distance, 1) + "cm)";
  }
  
  logPrint(statusMsg);
  
  // Check if we're returning to start and have reached starting position
  if (returning_to_start && starting_position_recorded) {
    if (isAtStartingPosition(distFront)) {
      Serial.println("========================");
      Serial.println("STARTING POSITION REACHED!");
      Serial.print("Current front distance: ");
      Serial.print(distFront, 1);
      Serial.print("cm (Target: ");
      Serial.print(starting_front_distance, 1);
      Serial.println("cm)");
      Serial.println("MISSION COMPLETE - STOPPING VEHICLE");
      Serial.println("========================");
      
      stopMotors();
      while (true) {
        delay(1000);
        Serial.println("Vehicle stopped at starting position");
      }
    }
  }
  
  // Check lap completion
  checkLapCompletion();
  
  // Main navigation logic with left/right turn
  if (distFront < FRONT_STOP_CM) {
    // Too close - move backward to safe distance first
    Serial.println("EMERGENCY: Too close to obstacle!");
    moveBackwardToSafeDistance();
    return; // Skip rest of loop iteration
  }
  else if (distFront < RIGHT_TURN_FRONT_CM && distRight > RIGHT_OPEN_CM) {
      // Right turn
      Serial.println("Front obstacle detected, right open, turning right 90 degrees");
      turnRight90Degrees();
      driveForward(DRIVE_SPEED);
      delay(300);
    }
  else if (distFront < LEFT_TURN_FRONT_CM && distRight < RIGHT_OPEN_CM) {
      // Left turn
      Serial.println("Front obstacle detected, right blocked, turning left");
      leftTurn();
      driveForward(DRIVE_SPEED);
      delay(300);
    }
  else if (distRight > RIGHT_OPEN_CM) {
    // If right sensor detects opening (>90cm) AND no front obstacle, continue straight
    Serial.println("Right opening detected, going straight");
    straightenSteering();
    driveForward(DRIVE_SPEED);
  } 
  else {
    // Default: drive forward
    Serial.println("Driving forward");
    straightenSteering();
    driveForward(DRIVE_SPEED);
  }
  
  delay(100); // Control loop timing
}

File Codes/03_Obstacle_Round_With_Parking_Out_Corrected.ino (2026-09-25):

// WRO FE 2026 - Obstacle STEP 5 v12 = v11 + heading PD (KP/KD, max corr) on all straight segments. v11 = forward-distance gate, front-approach gate, red-overlapping-orange ignored, set-up skip/fallback (full lock to +/-EXIT_TURN_DEG, straight EXIT_MM, opposite lock back to 0), side auto from L/R ToF. LINE_SEARCH creep when the line is missing, 'closed' side = seen closed in last SIDE_CLOSED_MM, slow near walls, 70 for set-up/turn/reverse (rear ToF on mux ch 6; FIRST_LEG_MIN_MM for the first corner; optional per-bulge leg minimums): straight-run bulges (v7) + gated precision corners (corner test v1).
// Leg = STRAIGHT (pillar trigger armed) -> BULGE (locked) -> SETTLE -> STRAIGHT ... -> CORNER when ALL gates pass:
//   distance gate (leg >= LEG_MIN_MM), sides gate (turn side open on 2 readings, other side closed, car within CORNER_MAX_ERR of lane),
//   front gate (F <= CORNER_TRIGGER_CM), line gate (clockwise: BLUE seen >= LINE_MIN_W wide in last LINE_WINDOW_MM; anticlockwise: ORANGE; first corner: either), not in any manoeuvre.
// Corner = STOP + measure -> ADJUST to FRONT_SET_CM -> TURN 90 (forward arc) -> REVERSE until rear ToF reads REAR_SET_CM (or REVERSE_MM if REAR_SET_CM is 0 / rear out of range) -> next leg.
#include <ESP32Servo.h>
#include <Wire.h>
#include <Adafruit_Sensor.h>
#include <Adafruit_BNO055.h>
#include <Adafruit_VL53L0X.h>
#include <Adafruit_NeoPixel.h>
#include <BluetoothSerial.h>
#include "HUSKYLENS.h"

#define IN1_PIN        26
#define IN2_PIN        27
#define SERVO_PIN      13
#define NEOPIXEL_PIN   14
#define START_BTN_PIN  25
#define ENCODER_A_PIN  18
#define ENCODER_B_PIN  19
#define TCAADDR        0x70
#define TOF_FRONT_CH   0
#define TOF_RIGHT_CH   1
#define TOF_LEFT_CH    2
#define TOF_REAR_CH    6
#define BNO_CH         3

// ---- parking exit (runs first, then the normal run) ----
#define USE_PARKING_EXIT     1    // 1 = do the exit at START; 0 = start straight as before
#define EXIT_DIR             0    // +1 exit to the right, -1 to the left, 0 = auto (toward the side that reads farther at START)
#define EXIT_LOCK_DEG       38    // steering offset for both exit arcs
#define EXIT_TURN_DEG       90    // arc 1: turn until the heading reaches this
#define EXIT_MM            100    // straight at the exit angle
#define EXIT_BACK_DEG        0    // arc 2: turn back until the heading reaches this (a few degrees > 0 releases earlier if it overshoots)
#define EXIT_EARLY_DEG       4    // release each exit arc this many degrees early
#define EXIT_SPEED          80
// ---- pillar / bulge ----
#define TRIGGER_BOTTOM     130    // start the bulge when the pillar's bottom (y + h/2) reaches this
#define TRIGGER_FRAMES       3
#define TRIGGER_MAX_TURN     5    // only trigger within this many degrees of the lane heading
#define MIN_PILLAR_H        12
#define PILLAR_MAX_W       110    // a pillar block is never wider than this (near pillars 55-83)
#define PILLAR_HW_MIN      1.0    // pillar: h >= w (a real red pillar close up was 79x94); the orange-as-red block is caught by the overlap rule instead
#define RED_ORANGE_OVERLAP  40    // a red block within this many px (x and y) of an orange block is the orange line mis-read as red: not a pillar
#define CENTER_TOL        0.12
#define THETA_CENTER        45
#define THETA_FAR           65
#define THETA_NEAR          30
#define PEAK_MM            250
#define BULGE_SERVO_DEG     38    // mirrored limits below are +/-38
#define EXIT_EARLY_DEG       5    // overshoot after a lock flip is ~3 deg (opposite lock stops the rotation)
#define SETTLE_MM          200    // straight after a bulge, nothing armed
#define MAX_BULGES_PER_LEG   2
// ---- corner gates ----
#define LEG_MIN_MM        2400    // corner allowed only after this encoder distance from the last corner's reverse point (any number of bulges)
#define USE_FWD_GATE         1    // 1 = also require the forward-projected distance fwd >= FWD_MIN_MM (bulges don't inflate it)
#define FWD_MIN_MM        3000    // real corners in the logs: fwd 3415-4445; the false one: 1976
#define APPROACH_CM        100    // front-approach gate: F must have read between CORNER_TRIGGER_CM and this ...
#define APPROACH_MM        300    // ... within the last this many mm before it reads <= CORNER_TRIGGER_CM (a wall comes gradually, a pillar jumps in)
#define SETUP_SKIP_CM        8    // skip the set-up move when |F - FRONT_SET_CM| <= this
#define FIRST_LEG_MIN_MM   300    // first corner only: the car starts mid-section, so the first wall can come much sooner
#define USE_BULGE_LEGS       0    // 0 = distance gate uses LEG_MIN_MM for every leg; 1 = uses LEG_MM_0/1/2 by the number of bulges in this leg
#define LEG_MM_0          2400    // USE_BULGE_LEGS=1: no bulge in this leg
#define LEG_MM_1          3200    // USE_BULGE_LEGS=1: one bulge
#define LEG_MM_2          4000    // USE_BULGE_LEGS=1: two bulges
#define USE_LINE_GATE        1    // 0 = corner does not need a line (lines still logged); 1 = line gate + LINE_SEARCH active
#define LINE_ANY_COLOUR      1    // 1 = blue OR orange confirms a corner in both directions; 0 = blue clockwise / orange anticlockwise
#define ORANGE_MIN_W        60    // orange reads narrower than blue (max ~100 in the logs); blue uses LINE_MIN_W
#define LINE_WINDOW_MM     600    // the line must have been seen within this travel
#define LINE_WINDOW2_MM   1500    // LINE_SEARCH fallback: if the creep reaches LINE_SEARCH_MIN_CM without a line, accept the corner if the line was seen within this
#define LINE_SEARCH_MIN_CM  25    // LINE_SEARCH: creep forward until the line shows, or until F reaches this
#define SIDE_CLOSED_MM     500    // the other side counts as closed if it read < SIDE_OPEN_CM at any point in the last this many mm
#define NEAR_WALL_CM        80    // on a straight, slow down to NEAR_SPEED when F is below this
#define NEAR_SPEED          80
#define LINE_MIN_W         130    // a line block must be at least this wide (near pillars reach ~110)
#define SIDE_OPEN_CM        70    // side reads open when > this (999 counts)
#define SIDE_OPEN_COUNT      2
#define CORNER_MAX_ERR       5    // car within this many degrees of the lane heading
#define CORNER_TRIGGER_CM   60    // front <= this
#define SAFETY_STOP_CM      12    // front this close with gates failing -> stop the run
// ---- corner sequence ----
#define TURN_DIR             0    // +1 right / -1 left / 0 auto: locked at the first corner from the open side
#define FRONT_SET_CM        50    // distance to set from the front wall before the turn
#define FRONT_TOL_CM         1
#define ADJUST_SPEED        80
#define TURN_DEG            90
#define TURN_SERVO_DEG      38
#define TURN_EARLY_DEG      18
#define TURN_SPEED          80
#define REAR_SET_CM          0    // after the turn, reverse until the rear ToF reads this (0 = ignore rear, use REVERSE_MM)
#define REAR_TOL_CM          2
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

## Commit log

2026-08-12 README for Obstacle-Avoiding Robot project
    Updated the README to reflect changes in project name, system architecture, hardware BOM, and installation instructions.
2026-08-12 Add WRO robot project files
    [Mohan drive V2.stl, WRO_Future_Engineers_BOM.xlsx, shaft.stl]
2026-09-18 Add Future Engineers V2 documentation and STL library
    [2 Pc V2 coupler for stering FE.stl, 2 pcs Diff Coupler for carbon rod.stl, Camera Mount For FE.stl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]
2026-09-23 Delete hardware/WRO_Future_Engineers_BOM.xlsx
    This one is outdated
    [WRO_Future_Engineers_BOM.xlsx]
2026-09-23 Delete hardware/CAD directory
    Outdated list of stl files
    [Mohan drive V2.stl, shaft.stl]
2026-09-24 Add corrected obstacle round code with parking out
    [03_Obstacle_Round_With_Parking_Out_Corrected.ino]
2026-09-25 Add build and bring-up procedure to README
    Added a detailed build and bring-up procedure for the robot assembly, including steps for wiring, calibration, and testing.
2026-09-25 Fix logging and add flush in step 5
    [02_Obstacle_Round_No_Parking_Slow_Accurate.ino]
